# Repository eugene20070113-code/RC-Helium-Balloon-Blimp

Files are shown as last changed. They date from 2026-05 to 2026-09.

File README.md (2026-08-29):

# RC-Helium-Balloon-Blimp

ESP32-C3 SuperMini based RC helium balloon blimp prototype. This project uses a DRV8833 motor driver to control two 720 coreless motors, and uses the Dabble mobile app GamePad module as the Bluetooth remote controller.

The current stage focuses on making the blimp move smoothly by using differential thrust. The left and right motors can run forward, backward, and at different speeds, allowing straight movement and wide-radius turning.

## Current Status

| Item | Current Setting |
| --- | --- |
| Main controller | ESP32-C3 SuperMini |
| Motor driver | DRV8833 |
| Motors | Two 720 coreless motors |
| Remote-control app | Dabble |
| Dabble module | GamePad |
| Bluetooth device name | `Innovation_Balloon` |
| Development environment | VS Code + PlatformIO |
| PlatformIO environment | `esp32-c3-supermini` |
| Main firmware file | `src/main.cpp` |
| Arduino sketch copies | `sketch_may14a.ino`, `arduino/sketch_may14a/sketch_may14a.ino` |

## Main Design Idea

The blimp uses two side motors instead of a steering rudder. Movement is controlled by changing the thrust of the left and right motors:

- Forward: both motors push forward at the same speed.
- Backward: both motors reverse at the same speed.
- Left turn: right motor runs faster than the left motor.
- Right turn: left motor runs faster than the right motor.
- Arc movement: forward or backward movement is combined with left/right turning.

This turning method is more suitable for a helium blimp because it avoids sudden in-place spinning. The current firmware uses wide-radius turns so the motion is smoother and easier to control.

## Hardware List

#### Control Electronics
- ESP32-C3 SuperMini
- DRV8833 motor driver module
- External motor battery

#### Motors and Propulsion
- Two 720 coreless motors
- Orbz balloon (structural body)
- Helium (lifting gas)

#### Protection Components
- 104 ceramic capacitors (2x)
- 100uF electrolytic capacitor

#### Remote Control Options
- **Option 1**: Smartphone via Dabble app (Bluetooth)
- **Option 2**: ESP32 + Mushroom joystick transmitter

### Wiring

### 1. Power Center and Main Switch

The battery first goes through the slide switch, then enters the breadboard power rail. This makes the switch the main power control for the whole system.

| Wire / Pin | Destination | Purpose |
| --- | --- | --- |
| Battery black wire / negative | Breadboard blue GND rail | Common ground |
| Battery red wire / positive | Center pin of the 3-pin slide switch | Power input to switch |
| Left or right output pin of slide switch | Breadboard red VCC rail | Switched power output |

After this step, the breadboard red rail is the main `VCC`, and the blue rail is the main `GND`.

### 2. ESP32-C3 SuperMini Power

| ESP32-C3 SuperMini | Destination | Note |
| --- | --- | --- |
| 5V | Breadboard red VCC rail | Use this pin for the current wiring |
| GND | Breadboard blue GND rail | Shared ground |

Important: do not connect the main power rail to the ESP32-C3 `3V3` pin. The current wiring plan powers the board through `5V`.

### 3. DRV8833 Power and Enable

| DRV8833 Pin | Destination | Purpose |
| --- | --- | --- |
| VCC | Breadboard red VCC rail | Motor driver power |
| GND | Breadboard blue GND rail | Shared ground |
| EEP | Breadboard red VCC rail | Enable / wake line |

The `EEP` pin must be connected to VCC. If `EEP` is not connected, the DRV8833 may stay disabled and the motors will not run even if the signal wires are correct.

### 4. ESP32-C3 to DRV8833 Signal Wiring

| ESP32-C3 GPIO | DRV8833 Input | Firmware Constant | Motor Side |
| --- | --- | --- | --- |
| GPIO4 | IN1 | `IN1` | Left motor forward side |
| GPIO5 | IN2 | `IN2` | Left motor backward side |
| GPIO6 | IN3 | `IN3` | Right motor forward side |
| GPIO7 | IN4 | `IN4` | Right motor backward side |

The firmware uses `analogWrite()` on these pins to control motor speed through PWM.

### 5. Motor Output Wiring

| Motor | DRV8833 Output |
| --- | --- |
| Left 720 coreless motor | OUT1 and OUT2 |
| Right 720 coreless motor | OUT3 and OUT4 |

If one motor spins in the wrong direction, swap the two wires of that motor on the DRV8833 output. If both motors move backward when pressing forward, the direction can also be corrected in firmware.

## Capacitors and Protection

| Component | Placement | Polarity | Purpose |
| --- | --- | --- | --- |
| 100uF electrolytic capacitor | Near DRV8833, between VCC and GND rails | Long leg to VCC, short leg / stripe side to GND | Helps stabilize motor power |
| 104 ceramic capacitor | Across the left motor terminals | No polarity | Reduces motor electrical noise |
| 104 ceramic capacitor | Across the right motor terminals | No polarity | Reduces motor electrical noise |

The 720 coreless motors can create electrical noise and sudden current changes. The capacitors help reduce noise and make the power supply more stable, especially when the motors start moving.

### Remote Control

The blimp supports two wireless control methods:

#### Method 1: Smartphone (Dabble App)
- Uses Bluetooth wireless connection
- Control via mobile device running Dabble app
- Suitable for quick testing and demonstrations

#### Method 2: ESP32 + Mushroom Joystick
- Uses a separate ESP32 transmitter with mushroom joystick
- Direct wireless control between two ESP32 boards
- More ergonomic for extended flying sessions
- Better range and reliability for field operations

### Current Test Program

### Bluetooth Control

The firmware uses Dabble ESP32 with custom settings enabled:

```cpp
#define CUSTOM_SETTINGS
#define INCLUDE_GAMEPAD_MODULE
#include <DabbleESP32.h>
```

The Bluetooth name shown in the Dabble app is:

```cpp
Dabble.begin("Innovation_Balloon");
```

### Speed Settings

```cpp
const int CRUISE_SPEED = 255;
const int TURN_FAST_SPEED = 255;
const int TURN_SLOW_SPEED = 120;
const int RAMP_SPEED = 15;
```

| Constant | Meaning |
| --- | --- |
| `CRUISE_SPEED` | Speed used for straight forward/backward movement |
| `TURN_FAST_SPEED` | Speed of the outside motor during turning |
| `TURN_SLOW_SPEED` | Speed of the inside motor during turning |
| `RAMP_SPEED` | Maximum speed change per loop cycle |

PWM speed values range from `0` to `255`.

### Soft-Start / Smooth Acceleration

The firmware does not immediately jump from `0` to full speed. Instead, it stores the current motor speed in:

```cpp
int currentLeftSpeed = 0;
int currentRightSpeed = 0;
```

The `drive()` function gradually moves the current speed toward the target speed by `RAMP_SPEED`. This reduces sudden motor startup current and helps prevent ESP32-C3 resets caused by voltage drops.

### Control Behavior

| Dabble GamePad Input | Left Motor | Right Motor | Blimp Movement |
| --- | --- | --- | --- |
| Up | Forward fast | Forward fast | Straight forward |
| Down | Backward fast | Backward fast | Straight backward |
| Left | Forward slow | Forward fast | Wide left turn |
| Right | Forward fast | Forward slow | Wide right turn |
| Up + Left | Forward slow | Forward fast | Forward left arc |
| Up + Right | Forward fast | Forward slow | Forward right arc |
| Down + Left | Backward slow | Backward fast | Backward left arc |
| Down + Right | Backward fast | Backward slow | Backward right arc |
| No button | Ramps down to 0 | Ramps down to 0 | Smooth stop |

## PlatformIO / VS Code

This project is configured for VS Code with PlatformIO.

| Setting | Value |
| --- | --- |
| PlatformIO environment | `esp32-c3-supermini` |
| Board | `esp32-c3-devkitm-1` |
| Framework | Arduino |
| Upload port | `COM10` |
| Monitor port | `COM10` |
| Monitor speed | `115200` |

Build command:

```powershell
C:\Users\01034\.platformio\penv\Scripts\pio.exe run
```

The latest build result was successful.

## Testing Checklist

1. Confirm the battery negative line is connected to the breadboard GND rail.
2. Confirm the battery positive line goes through the slide switch before reaching the VCC rail.
3. Confirm ESP32-C3 uses `5V` and `GND`.
4. Confirm DRV8833 `VCC`, `GND`, and `EEP` are connected.
5. Confirm GPIO4, GPIO5, GPIO6, and GPIO7 match IN1, IN2, IN3, and IN4.
6. Confirm the 100uF capacitor polarity is correct.
7. Confirm each 104 capacitor is soldered across the motor terminals.
8. Upload the firmware.
9. Open Dabble and connect to `Innovation_Balloon`.
10. Test without propellers first.
11. Press each direction button briefly and confirm the motor direction.

## Troubleshooting

| Problem | Possible Cause | Fix |
| --- | --- | --- |
| Motors do not move | DRV8833 `EEP` not connected | Connect `EEP` to VCC |
| ESP32-C3 resets when motors start | Motor startup current causes voltage drop | Check capacitor, battery strength, and lower speed/ramp settings |
| One motor spins backward | Motor output wires reversed | Swap the two wires of that motor |
| Left/right control feels reversed | Motor side or output direction is reversed | Swap motor wires or adjust firmware |
| Dabble cannot find the board | Bluetooth not started or wrong board powered | Check ESP32-C3 power and look for `Innovation_Balloon` |
| Upload fails | Wrong COM port | Check Device Manager or PlatformIO port setting |

## Progress Reports

- [2026-05-29 Dabble Remote Control and Final Wiring](docs/progress-2026-05-29.md)
- [2026-05-26 Current Progress Report](docs/progress-2026-05-26.md)
- [2026-05-22 Differential Motor Test](docs/progress-2026-05-22.md)

## Safety Notes

This project can be opened in VS Code with PlatformIO.

- Environment: `esp32-c3-supermini`
- Upload port: `COM10`
- Serial monitor speed: `115200`

### Arduino IDE

The same logic is also available in the Arduino IDE sketch:

`arduino/sketch_may14a/sketch_may14a.ino`

---

## 📄 License

This project is licensed under the MIT License - see the [LICENSE](LICENSE) file for details.

---

## 📞 Contact & Support

If you have any technical questions or suggestions, please contact us through:
- 📧 Email: eugene20070113@gmail.com
- 💬 Issues: [GitHub Issues](https://github.com/eugene20070113-code/RC-Helium-Balloon-Blimp/issues)

---

## 中文

### 專案簡介

本專案是使用 ESP32-C3 SuperMini 製作的氦氣飛船馬達控制原型。系統透過 DRV8833 馬達驅動模組控制兩顆 720 空心杯馬達。兩顆馬達分別安裝在飛船左右兩側，藉由左右推力差實現前進、後退與轉向。

### 使用硬體

#### 控制電子元件
- ESP32-C3 SuperMini
- DRV8833 馬達驅動模組
- 外接馬達電池

#### 馬達與推進系統
- 兩顆 720 空心杯馬達
- Orbz 氣球（結構體）
- 氦氣（升力氣體）

#### 保護元件
- 104 陶瓷電容 (2個)
- 100uF 電解電容

#### 遙控方式
- **方案 1**：手機 Dabble app 遙控（藍牙無線）
- **方案 2**：ESP32 + 蘑菇搖桿遙控

### 接線

#### ESP32-C3 接 DRV8833

| ESP32-C3 SuperMini | DRV8833 | 說明 |
| --- | --- | --- |
| GPIO4 | IN1 | 左馬達控制 1 |
| GPIO5 | IN2 | 左馬達控制 2 |
| GPIO6 | IN3 | 右馬達控制 1 |
| GPIO7 | IN4 | 右馬達控制 2 |
| 3V3 | EEP | 啟用 DRV8833 |
| GND | GND | 共地 |

#### 馬達與電源

| DRV8833 | 接法 |
| --- | --- |
| VCC | 馬達電池正極 |
| GND | 馬達電池負極 |
| OUT1, OUT2 | 左馬達 |
| OUT3, OUT4 | 右馬達 |

ESP32-C3 的 GND、DRV8833 的 GND、馬達電池負極必須接在一起，也就是共地。

### 電容配置

| 元件 | 位置 | 作用 |
| --- | --- | --- |
| 104 陶瓷電容 | 並聯在左馬達兩端 | 降低馬達雜訊 |
| 104 陶瓷電容 | 並聯在右馬達兩端 | 降低馬達雜訊 |
| 100uF 電解電容 | 接在 DRV8833 VCC 與 GND 之間 | 穩定馬達電源 |

104 陶瓷電容沒有正負極。100uF 電解電容有正負極，正極接 DRV8833 VCC，負極接 DRV8833 GND。

### 遙控控制

飛船支援兩種無線控制方式：

#### 方案 1：手機 Dabble App
- 使用藍牙無線連接
- 透過執行 Dabble app 的手機進行控制
- 適合快速測試與演示

#### 方案 2：ESP32 + 蘑菇搖桿
- 使用另一塊 ESP32 搭配蘑菇搖桿作為發射器
- 兩塊 ESP32 之間的直接無線控制
- 操作更符合人體工學，適合長時間飛行
- 可提供更好的控制距離與可靠性

### 目前測試程式

目前程式會依照以下順序測試馬達：

1. 前進：左右馬達都以速度 `150` 正轉 1.5 秒。
2. 停止 2 秒。
3. 後退：左右馬達都以速度 `150` 反轉 1.5 秒。
4. 停止 2 秒。
5. 左轉：左馬達速度 `80`，右馬達速度 `170`，持續 1.5 秒。
6. 停止 2 秒。
7. 右轉：左馬達速度 `170`，右馬達速度 `80`，持續 1.5 秒。
8. 停止 3 秒後重複。

### PWM 速度設定

目前使用 PWM 控制馬達速度，數值範圍是 `0` 到 `255`。

```cpp
const int CRUISE_SPEED = 150;
const int TURN_SLOW_SPEED = 80;
const int TURN_FAST_SPEED = 170;
```

### 安全注意事項

- 初期桌上測試時不要安裝螺旋槳。
- 確認測試動作後，請拔掉馬達電池。
- 不要讓測試程式長時間連續運轉。
- 如果驅動板、馬達或電池明顯發熱，請立刻斷電。

### 進度報告

- [2026-05-22 雙馬達差速測試](docs/progress-2026-05-22.md)

### PlatformIO / VS Code

本專案可以使用 VS Code 搭配 PlatformIO 開啟。

- 環境：`esp32-c3-supermini`
- 燒錄埠：`COM10`
- 序列監控鮑率：`115200`

### Arduino IDE

相同邏輯也有 Arduino IDE 版本：

`arduino/sketch_may14a/sketch_may14a.ino`

---

## 📄 授權條款

本專案採用 MIT License 授權 - 詳見 [LICENSE](LICENSE) 文件。

---

## 📞 聯絡與支援

如有技術問題或建議，請通過以下方式聯絡：
- 📧 Email: eugene20070113@gmail.com
- 💬 Issues: [GitHub Issues](https://github.com/eugene20070113-code/RC-Helium-Balloon-Blimp/issues)

---

**Last Updated**: 2026年8月29日

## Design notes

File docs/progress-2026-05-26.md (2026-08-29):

# 2026-05-26 目前進度報告

日期：2026-05-26  
專案：RC Helium Balloon Blimp / 氦氣飛船馬達控制原型

## 1. 專案目標

本專案目前目標是製作一台以 ESP32-C3 SuperMini 為主控板的氦氣飛船原型，使用 DRV8833 馬達驅動模組控制左右兩顆 720 空心杯馬達。透過左右馬達不同推力，讓飛船可以完成前進、後退、左轉與右轉。

目前階段重點不是完整遙控，而是先確認「雙馬達差速控制」是否穩定可用。

## 2. 目前硬體配置

目前使用的主要零件如下：

| 零件 | 用途 |
| --- | --- |
| ESP32-C3 SuperMini | 主控板 |
| DRV8833 馬達驅動模組 | 控制左右兩顆馬達 |
| 720 空心杯馬達 x 2 | 左右推進馬達 |
| 104 陶瓷電容 x 2 | 降低馬達雜訊 |
| 100uF 電解電容 | 穩定馬達電源 |
| 外接馬達電池 | 提供馬達電源 |

## 3. 目前接線狀態

### ESP32-C3 SuperMini 與 DRV8833

| ESP32-C3 SuperMini | DRV8833 | 說明 |
| --- | --- | --- |
| GPIO4 | IN1 | 左馬達控制腳 1 |
| GPIO5 | IN2 | 左馬達控制腳 2 |
| GPIO6 | IN3 | 右馬達控制腳 1 |
| GPIO7 | IN4 | 右馬達控制腳 2 |
| 3V3 | EEP | 啟用 DRV8833 |
| GND | GND | 共地 |

### 馬達與電源

| DRV8833 | 連接位置 |
| --- | --- |
| VCC | 馬達電池正極 |
| GND | 馬達電池負極 |
| OUT1, OUT2 | 左馬達 |
| OUT3, OUT4 | 右馬達 |

ESP32-C3 的 GND、DRV8833 的 GND、馬達電池負極需要共地，否則控制訊號可能不穩定。

## 4. 電容安裝規劃

| 電容 | 安裝位置 | 目的 |
| --- | --- | --- |
| 104 陶瓷電容 | 並聯在左馬達兩端 | 降低馬達電刷雜訊 |
| 104 陶瓷電容 | 並聯在右馬達兩端 | 降低馬達電刷雜訊 |
| 100uF 電解電容 | 接在 DRV8833 VCC 與 GND 之間 | 穩定馬達供電 |

104 陶瓷電容沒有正負極。100uF 電解電容有正負極，正極接 DRV8833 VCC，負極接 DRV8833 GND。

## 5. 目前韌體狀態

目前程式已從原本的 Dabble 手機藍牙遙控測試，改成 DRV8833 雙馬達差速測試程式。

目前主要程式檔案：

| 檔案 | 狀態 |
| --- | --- |
| `src/main.cpp` | PlatformIO 主要編譯入口，目前是雙馬達差速測試版 |
| `sketch_may14a.ino` | Arduino sketch，目前也是雙馬達差速測試版 |
| `arduino/sketch_may14a/sketch_may14a.ino` | Arduino IDE 版本，同樣是雙馬達差速測試版 |
| `platformio.ini` | PlatformIO 設定，目標板為 ESP32-C3 |

目前 PlatformIO 設定如下：

```ini
[env:esp32-c3-supermini]
platform = espressif32
board = esp32-c3-devkitm-1
framework = arduino
upload_port = COM10
monitor_port = COM10
monitor_speed = 115200
```

## 6. 目前測試程式內容

目前韌體會自動循環執行以下動作：

1. 前進：左右馬達同時以速度 `150` 正轉 1.5 秒。
2. 停止 2 秒。
3. 後退：左右馬達同時以速度 `150` 反轉 1.5 秒。
4. 停止 2 秒。
5. 左轉：左馬達速度 `80`，右馬達速度 `170`，持續 1.5 秒。
6. 停止 2 秒。
7. 右轉：左馬達速度 `170`，右馬達速度 `80`，持續 1.5 秒。
8. 停止 3 秒，然後重複。

目前 PWM 速度設定：

```cpp
const int CRUISE_SPEED = 150;
const int TURN_SLOW_SPEED = 80;
const int TURN_FAST_SPEED = 170;
```

PWM 範圍是 `0` 到 `255`。目前速度設定偏保守，適合桌上測試與初期調機。

## 7. 目前完成項目

- 已建立 ESP32-C3 SuperMini + DRV8833 的雙馬達控制架構。
- 已將控制腳位整理為 GPIO4、GPIO5、GPIO6、GPIO7。
- 已加入左右馬達獨立 PWM 控制函式。
- 已完成前進、後退、左轉、右轉、停止等基本動作函式。
- 已將 PlatformIO 版本 `src/main.cpp` 與 Arduino sketch 版本保持為同一套測試邏輯。
- 已整理目前硬體接線與測試流程，方便放到 GitHub 追蹤進度。

## 8. 目前待確認項目

- 目前本機 PowerShell 找不到 `pio` 指令，因此這次尚未能用終端機執行 `pio run` 重新編譯驗證。
- 若使用 VS Code 的 PlatformIO 擴充套件，仍可嘗試從 PlatformIO 介面進行 Build / Upload。
- 需要實機確認左右馬達方向是否與程式假設一致。
- 需要確認左轉與右轉在實際飛船架構上是否符合預期。
- 需要確認 104 陶瓷電容與 100uF 電解電容是否已正確安裝。
- Git 工作區目前不是乾淨狀態，`sketch_may14a.ino` 有修改，且 `RC-Helium-Balloon-Blimp/` 是尚未追蹤的新資料夾。

## 9. 安全注意事項

- 初期測試建議不要安裝螺旋槳，避免馬達突然轉動造成危險。
- 每次測試完應拔除馬達電池。
- 如果 DRV8833、馬達或電池明顯發熱，應立即斷電。
- 不建議讓目前自動測試程式長時間連續運轉。
- 裝上螺旋槳前，應先確認馬達方向與轉向邏輯。

## 10. 下一步建議

1. 用 VS Code PlatformIO 或可用的 PlatformIO CLI 重新 Build，確認目前程式可編譯。
2. 上傳到 ESP32-C3，觀察序列埠輸出是否依序顯示 Forward、Backward、Turn left、Turn right。
3. 不裝螺旋槳，先確認左右馬達是否依照測試流程轉動。
4. 若方向相反，先交換馬達線或調整 `setMotor()` / `turnLeft()` / `turnRight()` 的控制邏輯。
5. 將馬達固定到飛船架構後，重新測試推力方向。
6. 調整 `CRUISE_SPEED`、`TURN_SLOW_SPEED`、`TURN_FAST_SPEED`，找出穩定且不過熱的速度。
7. 馬達控制穩定後，再加入手機藍牙或其他遙控方式。

## 11. 目前結論

截至 2026-05-26，專案已進入「雙馬達差速控制測試」階段。程式架構已經從單一馬達或 Dabble 遙控測試，轉為可控制左右兩顆馬達的自動測試流程。

目前最重要的下一步是完成編譯與實機測試，確認馬達方向、轉向邏輯與供電穩定性。確認雙馬達控制穩定後，才適合繼續整合遙控功能與飛船本體測試。

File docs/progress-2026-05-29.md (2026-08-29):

# Progress Report - 2026-05-29

Date: 2026-05-29

## English

### 1. Project Stage

The RC helium balloon blimp project has moved from basic two-motor testing to Bluetooth remote-control testing.

Before this update, the project mainly verified whether the ESP32-C3 SuperMini could drive two 720 coreless motors through the DRV8833 motor driver. Today, the firmware and wiring plan were updated so the motors can be controlled by the Dabble mobile app GamePad module.

The goal of this stage is to make the blimp easier to control before real flight testing. Instead of only running a fixed motor test sequence, the operator can now send live control commands from a phone.

### 2. Completed Hardware Wiring Plan

#### 2.1 Power Center and Main Switch

The battery is connected through a 3-pin slide switch before powering the breadboard rail. This gives the system a simple main power switch.

| Connection | Destination | Purpose |
| --- | --- | --- |
| Battery black wire / negative | Breadboard blue GND rail | Main ground line |
| Battery red wire / positive | Center pin of the 3-pin slide switch | Power input to switch |
| Slide switch output pin | Breadboard red VCC rail | Switched power output |

After this wiring, the breadboard red rail is treated as the main `VCC`, and the blue rail is treated as the main `GND`.

#### 2.2 ESP32-C3 SuperMini Power

| ESP32-C3 SuperMini | Destination | Note |
| --- | --- | --- |
| 5V | Breadboard red VCC rail | Main power input for the ESP32-C3 |
| GND | Breadboard blue GND rail | Shared ground |

Important note: the ESP32-C3 is connected through the `5V` pin in this wiring plan. The main power rail must not be connected to the `3V3` pin.

#### 2.3 DRV8833 Motor Driver and Enable Line

| DRV8833 Pin | Destination | Purpose |
| --- | --- | --- |
| VCC | Breadboard red VCC rail | Power input for motor driver |
| GND | Breadboard blue GND rail | Shared ground |
| EEP | Breadboard red VCC rail | Enable / wake line |

The `EEP` pin is required. If this pin is not connected to VCC, the DRV8833 can remain disabled and the motors may not move even when the control signals are correct.

#### 2.4 Capacitor Protection

| Component | Placement | Polarity | Purpose |
| --- | --- | --- | --- |
| 100uF electrolytic capacitor | Near the DRV8833 power rail | Long leg to VCC, short leg / stripe side to GND | Helps stabilize power during motor startup |
| 104 ceramic capacitor | Across the left motor terminals | No polarity | Reduces motor electrical noise |
| 104 ceramic capacitor | Across the right motor terminals | No polarity | Reduces motor electrical noise |

The 100uF capacitor is placed near the DRV8833 because the motors can draw sudden current when starting. The capacitor helps reduce voltage drops. The 104 ceramic capacitors are soldered directly across the motor terminals to reduce motor noise.

#### 2.5 Signal Wiring

| ESP32-C3 GPIO | DRV8833 Input | Firmware Constant | Function |
| --- | --- | --- | --- |
| GPIO4 | IN1 | `IN1` | Left motor forward control |
| GPIO5 | IN2 | `IN2` | Left motor backward control |
| GPIO6 | IN3 | `IN3` | Right motor forward control |
| GPIO7 | IN4 | `IN4` | Right motor backward control |

#### 2.6 Motor Output

| Motor | DRV8833 Output |
| --- | --- |
| Left 720 coreless motor | OUT1 and OUT2 |
| Right 720 coreless motor | OUT3 and OUT4 |

If a motor direction is reversed during testing, the two output wires of that motor can be swapped.

### 3. Firmware Files Updated

The same motor-control logic was updated in the PlatformIO firmware and Arduino sketch copies.

| File | Purpose |
| --- | --- |
| `src/main.cpp` | Main PlatformIO firmware used by VS Code |
| `sketch_may14a.ino` | Root Arduino sketch copy |
| `arduino/sketch_may14a/sketch_may14a.ino` | Arduino IDE sketch folder copy |
| `README.md` | Project wiring and usage documentation |
| `docs/progress-2026-05-29.md` | Today's progress report |

### 4. Firmware Changes

#### 4.1 Dabble GamePad Control

The firmware now uses the Dabble ESP32 library and only enables the GamePad module:

```cpp
#define CUSTOM_SETTINGS
#define INCLUDE_GAMEPAD_MODULE
#include <DabbleESP32.h>
```

The Bluetooth device name was updated to:

```cpp
Dabble.begin("Innovation_Balloon");
```

This is the name that should appear in the Dabble app when connecting from the phone.

#### 4.2 Motor Pin Definitions

The motor control pins are:

```cpp
const int IN1 = 4;
const int IN2 = 5;
const int IN3 = 6;
const int IN4 = 7;
```

These match the ESP32-C3 to DRV8833 signal wiring.

#### 4.3 Speed Settings

The current speed settings are:

```cpp
const int CRUISE_SPEED = 255;
const int TURN_FAST_SPEED = 255;
const int TURN_SLOW_SPEED = 120;
```

`CRUISE_SPEED` is used for straight movement. `TURN_FAST_SPEED` is used by the outside motor while turning. `TURN_SLOW_SPEED` is used by the inside motor while turning.

The current values are intentionally strong for testing motor response. These values may need to be reduced after the motors are installed on the actual blimp frame.

#### 4.4 Smooth Acceleration

The firmware now tracks actual motor output speed:

```cpp
int currentLeftSpeed = 0;
int currentRightSpeed = 0;
```

The ramp value is:

```cpp
const int RAMP_SPEED = 15;
```

Instead of instantly jumping to the target speed, the `drive()` function gradually increases or decreases the motor speed. This reduces sudden current draw and helps prevent power drop or ESP32-C3 reset when the motors start.

#### 4.5 Motor Output Function

The `setMotor()` function receives a speed value from `-255` to `255`.

- Positive speed: motor turns forward.
- Negative speed: motor turns backward.
- Zero speed: motor stops.

This makes the motor control easier to read because forward and backward movement can be represented by the sign of the speed value.

### 5. Control Logic

The `handleGamePad()` function reads the Dabble GamePad buttons:

```cpp
bool up = GamePad.isUpPressed();
bool down = GamePad.isDownPressed();
bool left = GamePad.isLeftPressed();
bool right = GamePad.isRightPressed();
```

Then it calculates target speed for the left and right motors.

| Dabble Input | Left Motor Target | Right Motor Target | Result |
| --- | --- | --- | --- |
| Up | `CRUISE_SPEED` | `CRUISE_SPEED` | Straight forward |
| Down | `-CRUISE_SPEED` | `-CRUISE_SPEED` | Straight backward |
| Left | `TURN_SLOW_SPEED` | `TURN_FAST_SPEED` | Wide left turn |
| Right | `TURN_FAST_SPEED` | `TURN_SLOW_SPEED` | Wide right turn |
| Up + Left | `TURN_SLOW_SPEED` | `TURN_FAST_SPEED` | Forward left arc |
| Up + Right | `TURN_FAST_SPEED` | `TURN_SLOW_SPEED` | Forward right arc |
| Down + Left | `-TURN_SLOW_SPEED` | `-TURN_FAST_SPEED` | Backward left arc |
| Down + Right | `-TURN_FAST_SPEED` | `-TURN_SLOW_SPEED` | Backward right arc |
| No button | `0` | `0` | Smooth stop |

The single left and right buttons do not perform sharp in-place rotation. Instead, both motors keep moving forward, but one side is slower. This creates a smoother and wider turning radius, which is more suitable for a helium blimp.

### 6. Current Result

The updated firmware is now in the VS Code / PlatformIO project. The PlatformIO build was tested successfully.

Build command used:

```powershell
C:\Users\01034\.platformio\penv\Scripts\pio.exe run
```

Build result:

```text
[SUCCESS] Took 18.30 seconds
```

This confirms that the updated `src/main.cpp` compiles correctly with the current PlatformIO setup and DabbleESP32 library.

### 7. Testing Plan

Recommended test sequence:

1. Confirm all power is off.
2. Check the battery negative line is connected to the GND rail.
3. Check the battery positive line enters the slide switch first.
4. Check the slide switch output goes to the VCC rail.
5. Check ESP32-C3 `5V` and `GND`.
6. Check DRV8833 `VCC`, `GND`, and `EEP`.
7. Check GPIO4 to IN1, GPIO5 to IN2, GPIO6 to IN3, and GPIO7 to IN4.
8. Check 100uF capacitor polarity.
9. Check both 104 capacitors on the motors.
10. Upload the firmware.
11. Open Dabble and connect to `Innovation_Balloon`.
12. Test each direction without propellers.
13. Confirm forward, backward, left arc, and right arc.
14. If a direction is wrong, fix motor wiring or adjust firmware direction.

### 8. Problems to Watch For

| Problem | Possible Cause | Fix |
| --- | --- | --- |
| Motors do not move | DRV8833 `EEP` is not connected | Connect `EEP` to VCC |
| ESP32-C3 restarts when motors start | Voltage drop from motor startup current | Check battery, capacitor, and reduce speed/ramp settings |
| One motor direction is reversed | Motor output wires are reversed | Swap the two output wires of that motor |
| Left and right controls are reversed | Motor sides or output direction are reversed | Swap motor connections or adjust code |
| Dabble cannot connect | Bluetooth name not found or ESP32 not powered | Check power and search for `Innovation_Balloon` |
| Motor noise affects control | Capacitors missing or wiring too loose | Recheck 104 capacitors and common ground |

### 9. Next Steps

1. Upload the firmware to the ESP32-C3 through PlatformIO.
2. Test Dabble connection and button response.
3. Test motor direction without propellers.
4. Mount the motors on the blimp frame.
5. Test the same controls after mounting.
6. Tune `CRUISE_SPEED`, `TURN_FAST_SPEED`, and `TURN_SLOW_SPEED`.
7. Tune `RAMP_SPEED` if acceleration is too slow or still causes power drops.
8. Record real flight-frame test results in the next progress report.

## 中文

### 1. 專案階段

RC 氦氣飛船專案今天從「雙馬達基本測試」進入「藍牙遙控測試」階段。

前一階段主要確認 ESP32-C3 SuperMini 是否能透過 DRV8833 馬達驅動模組控制兩顆 720 空心杯馬達。今天的重點是把固定測試流程改成手機即時遙控，讓操作者可以透過 Dabble App 的 GamePad 模組控制飛船前進、後退與轉向。

這個階段的目標是讓飛船在實際飛行測試前，先具備比較穩定、可重複操作的遙控能力。

### 2. 今日完成的硬體接線規劃

#### 2.1 能源中心與總開關

電池會先進入 3 腳滑動開關，再由開關輸出到麵包板電源軌。這樣整個系統就有一個主電源開關。

| 接線 | 接到 | 目的 |
| --- | --- | --- |
| 電池黑線 / 負極 | 麵包板藍色總地線軌 GND | 系統共同地線 |
| 電池紅線 / 正極 | 3 腳滑動開關的正中間腳位 | 開關電源輸入 |
| 滑動開關左邊或右邊輸出腳 | 麵包板紅色總電源軌 VCC | 開關後的系統電源 |

完成後，麵包板紅色軌視為整個系統的 `VCC`，藍色軌視為整個系統的 `GND`。

#### 2.2 ESP32-C3 SuperMini 供電

| ESP32-C3 SuperMini | 接到 | 說明 |
| --- | --- | --- |
| 5V | 麵包板紅色總電源軌 VCC | 目前接線使用的供電腳 |
| GND | 麵包板藍色總地線軌 GND | 與馬達驅動共地 |

重要注意：目前接法是把電源接到 ESP32-C3 的 `5V` 腳位，絕對不能把主電源軌接到 `3V3` 腳位。

#### 2.3 DRV8833 馬達驅動與喚醒線

| DRV8833 腳位 | 接到 | 目的 |
| --- | --- | --- |
| VCC | 麵包板紅色總電源軌 VCC | 馬達驅動電源 |
| GND | 麵包板藍色總地線軌 GND | 系統共同地線 |
| EEP | 麵包板紅色總電源軌 VCC | 啟用 / 喚醒 DRV8833 |

`EEP` 是非常重要的喚醒線。若沒有接到 VCC，DRV8833 可能會維持關閉狀態，即使 ESP32-C3 有送控制訊號，馬達也不會動。

#### 2.4 電容防護

| 元件 | 位置 | 正負極 | 作用 |
| --- | --- | --- | --- |
| 100uF 電解電容 | 靠近 DRV8833 的 VCC 與 GND 電源軌之間 | 長腳接 VCC，短腳 / 白條紋側接 GND | 穩定馬達啟動時的電源 |
| 104 陶瓷電容 | 左馬達兩個接點之間 | 不分正負極 | 降低馬達雜訊 |
| 104 陶瓷電容 | 右馬達兩個接點之間 | 不分正負極 | 降低馬達雜訊 |

720 空心杯馬達啟動時可能會產生瞬間電流變化與電氣雜訊。100uF 電解電容用來幫助穩定供電，104 陶瓷電容則用來降低馬達端產生的雜訊。

#### 2.5 訊號線

| ESP32-C3 GPIO | DRV8833 輸入 | 程式常數 | 功能 |
| --- | --- | --- | --- |
| GPIO4 | IN1 | `IN1` | 左馬達前進控制 |
| GPIO5 | IN2 | `IN2` | 左馬達後退控制 |
| GPIO6 | IN3 | `IN3` | 右馬達前進控制 |
| GPIO7 | IN4 | `IN4` | 右馬達後退控制 |

#### 2.6 動力輸出

| 馬達 | DRV8833 輸出 |
| --- | --- |
| 左 720 空心杯馬達 | OUT1 與 OUT2 |
| 右 720 空心杯馬達 | OUT3 與 OUT4 |

如果測試時某一顆馬達方向相反，可以直接對調該馬達接在 DRV8833 輸出的兩條線。

### 3. 今日更新的檔案

| 檔案 | 用途 |
| --- | --- |
| `src/main.cpp` | VS Code / PlatformIO 使用的主要程式 |
| `sketch_may14a.ino` | 根目錄 Arduino sketch 備份 |
| `arduino/sketch_may14a/sketch_may14a.ino` | Arduino IDE sketch 資料夾版本 |
| `README.md` | 專案接線、功能與使用說明 |
| `docs/progress-2026-05-29.md` | 今日進度紀錄 |

### 4. 程式更新內容

#### 4.1 加入 Dabble GamePad 藍牙遙控

程式使用 Dabble ESP32 函式庫，並只啟用 GamePad 模組：

```cpp
#define CUSTOM_SETTINGS
#define INCLUDE_GAMEPAD_MODULE
#include <DabbleESP32.h>
```

藍牙裝置名稱設定為：

```cpp
Dabble.begin("Innovation_Balloon");
```

手機 Dabble App 連線時，應該尋找 `Innovation_Balloon` 這個名稱。

#### 4.2 馬達腳位定義

目前程式使用的馬達控制腳位如下：

```cpp
const int IN1 = 4;
const int IN2 = 5;
const int IN3 = 6;
const int IN4 = 7;
```

這四個腳位對應到 ESP32-C3 與 DRV8833 的訊號接線。

#### 4.3 速度參數

目前速度設定如下：

```cpp
const int CRUISE_SPEED = 255;
const int TURN_FAST_SPEED = 255;
const int TURN_SLOW_SPEED = 120;
```

`CRUISE_SPEED` 用於直線前進或後退。`TURN_FAST_SPEED` 是轉彎時外側馬達的速度。`TURN_SLOW_SPEED` 是轉彎時內側馬達的速度。

目前數值偏向測試最大推力與馬達反應。實際裝上飛船後，可能需要依照飛船重量、浮力、螺旋槳方向與電池狀態再調整。

#### 4.4 新增軟啟動與平滑加減速

程式新增兩個變數，用來記錄目前實際輸出的馬達速度：

```cpp
int currentLeftSpeed = 0;
int currentRightSpeed = 0;
```

加減速步進值設定為：

```cpp
const int RAMP_SPEED = 15;
```

馬達不會從 `0` 瞬間跳到 `255`，而是每次 loop 慢慢靠近目標速度。這樣可以降低啟動瞬間電流，讓 ESP32-C3 比較不容易因為電壓下降而重啟或斷電。

#### 4.5 馬達輸出函式

`setMotor()` 使用 `-255` 到 `255` 的速度值控制馬達：

- 正數代表正轉。
- 負數代表反轉。
- `0` 代表停止。

這樣設計後，前進與後退可以用速度的正負號表示，程式邏輯會比較清楚。

### 5. 遙控邏輯

`handleGamePad()` 會讀取 Dabble GamePad 的四個方向鍵：

```cpp
bool up = GamePad.isUpPressed();
bool down = GamePad.isDownPressed();
bool left = GamePad.isLeftPressed();
bool right = GamePad.isRightPressed();
```

接著依照按鍵組合計算左右馬達的目標速度。

| Dabble 輸入 | 左馬達目標 | 右馬達目標 | 飛船動作 |
| --- | --- | --- | --- |
| 上 | `CRUISE_SPEED` | `CRUISE_SPEED` | 直線前進 |
| 下 | `-CRUISE_SPEED` | `-CRUISE_SPEED` | 直線後退 |
| 左 | `TURN_SLOW_SPEED` | `TURN_FAST_SPEED` | 大半徑左轉 |
| 右 | `TURN_FAST_SPEED` | `TURN_SLOW_SPEED` | 大半徑右轉 |
| 上 + 左 | `TURN_SLOW_SPEED` | `TURN_FAST_SPEED` | 前進左弧線 |
| 上 + 右 | `TURN_FAST_SPEED` | `TURN_SLOW_SPEED` | 前進右弧線 |
| 下 + 左 | `-TURN_SLOW_SPEED` | `-TURN_FAST_SPEED` | 後退左弧線 |
| 下 + 右 | `-TURN_FAST_SPEED` | `-TURN_SLOW_SPEED` | 後退右弧線 |
| 無按鍵 | `0` | `0` | 平滑減速停止 |

單獨按左或右時，程式不是讓馬達原地反轉，而是讓左右兩顆馬達都往前轉，只是內側馬達較慢。這樣會形成比較自然的大半徑轉彎，比較適合氦氣飛船這種慣性較大、轉向不適合太急的載具。

### 6. 目前成果

最新版程式已經放入 VS Code / PlatformIO 專案中，並同步更新 Arduino sketch 備份。

使用的編譯指令：

```powershell
C:\Users\01034\.platformio\penv\Scripts\pio.exe run
```

編譯結果：

```text
[SUCCESS] Took 18.30 seconds
```

這代表 `src/main.cpp` 可以在目前 PlatformIO 環境下成功編譯，DabbleESP32 函式庫也有被正確引用。

### 7. 建議測試流程

1. 確認電源關閉。
2. 檢查電池黑線是否接到 GND 軌。
3. 檢查電池紅線是否先進入滑動開關中間腳。
4. 檢查滑動開關輸出是否接到 VCC 軌。
5. 檢查 ESP32-C3 是否接 `5V` 與 `GND`。
6. 檢查 DRV8833 的 `VCC`、`GND`、`EEP` 是否都有接好。
7. 檢查 GPIO4 到 IN1、GPIO5 到 IN2、GPIO6 到 IN3、GPIO7 到 IN4。
8. 檢查 100uF 電解電容正負極是否正確。
9. 檢查左右馬達是否各焊一顆 104 陶瓷電容。
10. 上傳最新版程式。
11. 開啟 Dabble App，連線 `Innovation_Balloon`。
12. 不安裝螺旋槳，先短按每個方向鍵測試馬達方向。
13. 確認前進、後退、左弧線、右弧線是否符合預期。
14. 若方向錯誤，先修正馬達線或程式方向，再進行下一步測試。

### 8. 可能遇到的問題

| 問題 | 可能原因 | 解決方式 |
| --- | --- | --- |
| 馬達完全不動 | DRV8833 `EEP` 沒有接到 VCC | 將 `EEP` 接到紅色 VCC 電源軌 |
| ESP32-C3 一啟動馬達就重啟 | 馬達啟動電流造成電壓下降 | 檢查電池、100uF 電容，或降低速度 / 調小加速幅度 |
| 某一顆馬達方向相反 | 馬達輸出線接反 | 對調該馬達的兩條線 |
| 左右控制相反 | 左右馬達位置或方向相反 | 對調左右馬達接線，或在程式調整方向 |
| Dabble 找不到裝置 | ESP32-C3 沒有正常供電或藍牙未啟動 | 檢查電源，重新搜尋 `Innovation_Balloon` |
| 馬達干擾導致控制不穩 | 電容未裝好或共地不良 | 檢查 104 電容、100uF 電容與 GND 共地 |

### 9. 下一步

1. 使用 PlatformIO 將程式上傳到 ESP32-C3。
2. 使用 Dabble App 實際連線測試。
3. 在不裝螺旋槳的情況下確認馬達方向。
4. 將馬達固定到飛船架構上。
5. 在飛船架構上再次測試前進、後退與轉向。
6. 根據飛船重量與推力調整 `CRUISE_SPEED`、`TURN_FAST_SPEED`、`TURN_SLOW_SPEED`。
7. 若起步仍然造成電壓下降，繼續調整 `RAMP_SPEED`。
8. 將實際裝機測試結果記錄到下一份進度報告。

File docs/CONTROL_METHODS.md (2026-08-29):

# 遙控控制方案詳解

本專案支援兩種無線遙控方案。本文件詳細說明每種方案的硬體配置、代碼部署和使用方式。

---

## 方案 1：手機 Dabble App 遙控 (Bluetooth)

### 特點
- ✅ 無需額外硬體
- ✅ 直接用手機控制
- ✅ 適合快速測試和演示
- ✅ 支援多種手機遊戲搖桿模擬

### 硬體需求
- 飛船：ESP32-C3 SuperMini
- 手機：iOS 或 Android
- 連接方式：Bluetooth 無線

### 軟體安裝
1. 手機下載 **Dabble** app
   - [iOS App Store](https://apps.apple.com/app/dabble-iot-for-arduino/id1461351821)
   - [Google Play Store](https://play.google.com/store/apps/details?id=io.dabble)

2. 飛船端代碼：`src/main.cpp` (原始測試版本)

### 使用流程
1. 將飛船代碼燒錄到 ESP32-C3 SuperMini
2. 打開手機 Dabble app
3. 點擊「Connect」搜尋藍牙設備
4. 選擇飛船的藍牙名稱並配對
5. 打開 Dabble 的「遊戲搖桿」功能
6. 用搖桿控制飛船的前進、後退、轉向

### 優點 & 缺點

| 方面 | 評價 |
|---|---|
| 成本 | 💰 最便宜（無需額外硬體） |
| 便利性 | ⭐⭐⭐⭐ 手機即拿即用 |
| 操控感 | ⭐⭐⭐ 可接受，但手機觸控不如物理搖桿 |
| 延遲 | ⚠️ 略高（Bluetooth 延遲約 50-100ms） |
| 有效距離 | 📍 ~10-15 公尺 |
| 適用場景 | 🏠 室內或近距離測試 |

---

## 方案 2：ESP32 + 香菇搖桿遙控 (ESP-NOW)

### 特點
- ✅ 專用硬體遙控器，操控更精確
- ✅ 香菇搖桿提供類比控制
- ✅ ESP-NOW 低延遲、高可靠性
- ✅ 更適合長時間飛行與精密操控

### 硬體需求

#### 飛船端 (接收器)
- **ESP32-C3 SuperMini**
- **DRV8833 馬達驅動模組**
- **2x 720 空心杯馬達**
- **Orbz 氣球**
- **保護元件**：2x 104 陶瓷電容 + 1x 100μF 電解電容

#### 遙控器端 (發射器)
- **ESP32** (大型版或 DevKit)
  - 需要模擬輸入腳位（ADC）
- **香菇搖桿模組**
  - VRx 連接 GPIO32
  - VRy 連接 GPIO33
  - +5V 和 GND 連接

### 硬體連接圖

#### 飛船端接線
```
ESP32-C3 SuperMini  ←→  DRV8833
GPIO4 (IN1)         ←→  IN1
GPIO5 (IN2)         ←→  IN2
GPIO6 (IN3)         ←→  IN3
GPIO7 (IN4)         ←→  IN4
3V3                 ←→  EEP
GND                 ←→  GND

DRV8833             ←→  馬達
OUT1, OUT2          ←→  左馬達
OUT3, OUT4          ←→  右馬達
VCC                 ←→  馬達電池 (+)
GND                 ←→  馬達電池 (-)
```

#### 遙控器端接線
```
香菇搖桿            ←→  ESP32
VRx                 ←→  GPIO32
VRy                 ←→  GPIO33
+5V                 ←→  5V
GND                 ←→  GND
```

### 代碼部署

#### 步驟 1：查詢飛船的 MAC 地址

1. 編譯並上傳飛船代碼：
   ```
   src/receiver_esp32_supermini/receiver.cpp
   ```

2. 打開 Serial Monitor（波特率：115200）

3. 查看輸出信息，找到飛船的 MAC 地址：
   ```
   🚁 飛船 ESP32-C3 SuperMini
   📡 MAC Address: 10:00:3B:CC:3E:6C
   ```

4. **記下這個 MAC 地址**（例如：10:00:3B:CC:3E:6C）

#### 步驟 2：配置遙控器代碼

1. 打開遙控器代碼：
   ```
   src/transmitter_esp32/transmitter.cpp
   ```

2. 找到這一行：
   ```cpp
   uint8_t broadcastAddress[] = {0xXX, 0xXX, 0xXX, 0xXX, 0xXX, 0xXX};
   ```

3. 根據步驟 1 的 MAC 地址替換：
   ```cpp
   // 範例：MAC 地址 10:00:3B:CC:3E:6C
   uint8_t broadcastAddress[] = {0x10, 0x00, 0x3B, 0xCC, 0x3E, 0x6C};
   ```

4. 保存並編譯

#### 步驟 3：燒錄代碼

1. 將飛船代碼燒錄到 **ESP32-C3 SuperMini**
2. 將遙控器代碼燒錄到 **ESP32 (遙控器)**
3. 分別打開兩個 Serial Monitor 查看狀態

### 使用流程

1. **啟動飛船**
   - 電源打開，飛船進入待機狀態
   - Serial Monitor 顯示：`⏳ 等待遙控器訊號...`

2. **啟動遙控器**
   - 打開遙控器電源
   - Serial Monitor 顯示：`✅ 遙控器已準備就緒！`
   - 等待與飛船配對

3. **開始控制**
   - 搖動香菇頭控制飛船
   - X 軸：左右轉向
   - Y 軸：前進/後退

4. **停止**
   - 將搖桿放回中心位置（自動歸零）
   - 如果超過 0.5 秒無訊號，飛船自動停止 (安全保護)

### 訊號協議

#### 訊號結構
```cpp
typedef struct struct_message {
  int x;           // 左右推力 (-255 到 255)
  int y;           // 前後推力 (-255 到 255)
  uint8_t checksum;// 校驗和 (防止訊號竄改)
} struct_message;
```

#### 校驗和機制
- 每個訊號都包含 CRC8 校驗和
- 接收端會驗證資料完整性
- 如果校驗失敗，訊號會被拒絕
- 這確保惡意或破損的訊號無法控制飛船

#### 更新頻率
- 遙控器每 20ms 發送一次訊號（~50 Hz）
- 飛船每 20ms 更新一次馬達控制
- 總延遲：< 50ms

### 優點 & 缺點

| 方面 | 評價 |
|---|---|
| 成本 | 💰💰 需購買額外硬體 (~USD 10-20) |
| 便利性 | ⭐⭐⭐⭐⭐ 專用搖桿，操控最直觀 |
| 操控感 | ⭐⭐⭐⭐⭐ 類比搖桿，精確度高 |
| 延遲 | ⚡ 極低 (< 50ms) |
| 有效距離 | 📍 ~100+ 公尺（取決於環境） |
| 適用場景 | 🌳 戶外飛行、長時間操控、精密控制 |

---

## 安全特性

### 所有方案共有

1. **斷訊保護**
   - 如果 0.5 秒內未收到訊號，飛船自動停止
   - 防止因連線中斷導致飛船失控

2. **死區防護**
   - 搖桿±20 以內的微小漂移被忽略
   - 防止手指離開搖桿時的無意輸入

3. **加速平滑**
   - 馬達速度逐步加速而非突然跳躍
   - 增加控制穩定性

4. **功率限制** (方案 2 特有)
   - 馬達速度被限制在 95-150 之間
   - 避免馬達在低電壓下發生故障

### 方案 2 額外安全機制

5. **校驗和驗證**
   - 每個訊號都有 CRC8 校驗和
   - 防止訊號竄改或損毀

6. **MAC 地址綁定**
   - 遙控器只能與指定的飛船通訊
   - 他人無法隨意控制你的飛船

---

## 控制邏輯說明

### 馬達混控系統

飛船採用「差分推力控制」，通過左右馬達速度差實現轉向：

```
leftMotor = throttle + steering
rightMotor = throttle - steering
```

- **throttle (X軸)**: 前進/後退
- **steering (Y軸)**: 左轉/右轉

### 轉向靈敏度

- 預設轉向靈敏度係數：`0.5`
- 這意味著轉向輸入會被削減一半
- 目的：確保轉向不會過度靈敏

如果你覺得轉向太靈或太遲鈍，可以修改這個值：
```cpp
const float STEERING_SENSITIVITY = 0.5;  // 改成 0.3 (更柔和) 或 0.7 (更靈敏)
```

---

## 故障排除

### 方案 1：Dabble 遙控

| 問題 | 解決方案 |
|---|---|
| 手機無法找到藍牙設備 | 檢查 ESP32 藍牙是否已啟用；嘗試重新啟動藍牙 |
| 控制延遲很高 | 靠近飛船；檢查是否有干擾；嘗試切換藍牙頻道 |
| 飛船不動 | 檢查馬達電池是否充電；確認所有接線無誤 |

### 方案 2：ESP32 + 搖桿遙控

| 問題 | 解決方案 |
|---|---|
| 遙控器找不到飛船 | 確認 MAC 地址是否正確；檢查飛船是否已上電 |
| Serial Monitor 顯示 "❌ MAC 地址未設置" | 用正確的飛船 MAC 替換 `0xXX` |
| 控制反應遲鈍 | 檢查搖桿是否損壞；嘗試重新校準ADC |
| 飛船突然停止 | 可能是訊號喪失 (斷訊保護)；檢查遙控器電源 |

---

## 推薦使用情景

### 選擇方案 1 (Dabble):
- 🏠 在家進行快速測試
- 👥 向朋友演示
- 📊 進行數據記錄和分析 (Dabble 有內建圖表)
- 🔧 調試馬達參數

### 選擇方案 2 (ESP32 + 搖桿):
- 🌳 戶外飛行測試
- ⏱️ 長時間操控 (搖桿不會因握持而疲勞)
- 🎯 精密飛行操控
- 🏆 競速或特技飛行

---

## 進階設置

### 修改馬達功率範圍

編輯 `receiver.cpp`：
```cpp
const int START_POWER = 95;       // 最低啟動推力
const int MAX_POWER = 150;        // 最高推力
```

- 降低 `MAX_POWER` → 飛船速度較慢但更穩定
- 提高 `MAX_POWER` → 飛船速度更快但消耗更多功率

### 調整轉向靈敏度

編輯 `receiver.cpp`：
```cpp
const float STEERING_SENSITIVITY = 0.5;
```

- 改成 `0.3` → 轉向變遲鈍 (適合初學者)
- 改成 `0.7` → 轉向變靈敏 (適合高手)

### 修改斷訊保護時間

編輯 `receiver.cpp`：
```cpp
if (millis() - lastRecvTime > 500) {  // 500ms
```

- 改成 `1000` → 允許 1 秒的訊號喪失時間
- 改成 `200` → 更靈敏的保護 (建議不要太短)

---

## 相關資源

- [ESP-NOW 官方文檔](https://docs.espressif.com/projects/esp-idf/en/latest/esp32/api-reference/network/esp_now.html)
- [Dabble 官方網站](https://thestempedia.com/dabble/)
- [ESP32 ADC 特性](https://docs.espressif.com/projects/esp-idf/en/latest/esp32/api-reference/peripherals/adc.html)

---

**最後更新**: 2026年8月29日

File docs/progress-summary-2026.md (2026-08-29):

# RC-Helium-Balloon-Blimp 專案進度總結

**最後更新**: 2026年8月29日

## 專案概述

RC直升機氣球/飛艇電機控制原型。使用ESP32-C3 SuperMini控制DRV8833馬達驅動器，以駕駛兩個720無芯馬達。

## 核心功能

- ✅ 雙馬達差分推力控制
- ✅ PWM速度控制（0-255）
- ✅ 前進、後退、轉向控制
- ✅ 馬達噪音減弱電路（去耦電容）

## 項目進度歷史

### 第1階段：初始設置 (提交: `df6b0e1`)
**狀態**: ✅ 完成
- 專案初始化
- 基礎硬體連線配置
- 文檔框架建立

**提交信息**: `feat: 完成單馬達藍牙遙控測試`

---

### 第2階段：單馬達藍牙遙控測試 (提交: `452175a`)
**狀態**: ✅ 完成
- 初始馬達測試專案建立
- 單馬達驅動測試
- 藍牙遙控基礎實現

**提交信息**: `Initial motor test project`

---

### 第3階段：差分馬達測試 (提交: `95198ef`)
**狀態**: ✅ 完成
- 升級為雙馬達控制
- 差分推力控制實現
- PWM速度控制參數設置

**測試序列**:
1. 前進：左右馬達速度150，1.5秒
2. 停止：2秒
3. 後退：左右馬達速度150，1.5秒
4. 停止：2秒
5. 左轉：左馬達速度80，右馬達速度170，1.5秒
6. 停止：2秒
7. 右轉：左馬達速度170，右馬達速度80，1.5秒
8. 停止：3秒

**測試結果**:
- ✅ 編譯成功
- ✅ 上傳成功
- ✅ 硬體檢測正常
- ✅ 馬達正常運作

**提交信息**: `Add differential motor test progress report`

---

### 第4階段：文檔改進 (提交: `366c047` - `23c984c`)
**狀態**: ✅ 完成
- 進度報告添加日期標記
- README.md雙語化（英文/中文）
- 文檔結構分離優化

**相關提交**:
- `366c047`: Add date to progress report
- `0e93481`: Make README bilingual
- `23c984c`: Separate English and Chinese documentation sections

---

## 硬體配置

### 主控制器
- **型號**: ESP32-C3 SuperMini
- **連接**: GPIO4-7 連接馬達驅動器

### 馬達驅動器
- **型號**: DRV8833 馬達驅動模塊
- **馬達**: 2x 720無芯馬達（左右側）

### 連線對應表

| ESP32-C3 | DRV8833 | 功能 |
|---|---|---|
| GPIO4 | IN1 | 左馬達控制1 |
| GPIO5 | IN2 | 左馬達控制2 |
| GPIO6 | IN3 | 右馬達控制1 |
| GPIO7 | IN4 | 右馬達控制2 |
| 3V3 | EEP | 啟用DRV8833 |
| GND | GND | 共同接地 |

### 保護元件

| 元件 | 位置 | 功能 |
|---|---|---|
| 104陶瓷電容 | 左馬達端子間 | 降低馬達電噪音 |
| 104陶瓷電容 | 右馬達端子間 | 降低馬達電噪音 |
| 100μF電解電容 | DRV8833 VCC/GND間 | 穩定馬達電源 |

## 當前韌體設置

### PWM速度參數
```cpp
const int CRUISE_SPEED = 150;      // 巡航速度
const int TURN_SLOW_SPEED = 80;    // 轉向慢速
const int TURN_FAST_SPEED = 170;   // 轉向快速
```

### PWM範圍
- 最小: 0
- 最大: 255

## 專案檔案結構

```
RC-Helium-Balloon-Blimp/
├── README.md                           # 項目說明（英文/中文）
├── platformio.ini                      # PlatformIO配置
├── sketch_may14a.ino                   # 主要草圖
├── src/
│   └── main.cpp                        # 主程式源碼
├── arduino/
│   └── sketch_may14a/
│       └── sketch_may14a.ino           # Arduino版本
└── docs/
    ├── progress-2026-05-22.md          # 階段進度報告
    └── progress-summary-2026.md        # 本文件
```

## GitHub提交日誌

| 提交ID | 信息 | 狀態 |
|---|---|---|
| `23c984c` | Separate English and Chinese documentation sections | ✅ main |
| `0e93481` | Make README bilingual | ✅ |
| `366c047` | Add date to progress report | ✅ |
| `95198ef` | Add differential motor test progress report | ✅ |
| `452175a` | Initial motor test project | ✅ |
| `df6b0e1` | feat: 完成單馬達藍牙遙控測試 | ✅ |

**目前分支**: main
**遠程狀態**: 最新（已同步）

## 已驗證功能

- ✅ ESP32-C3 可成功與DRV8833通訊
- ✅ GPIO控制引腳正常工作
- ✅ PWM速度控制有效
- ✅ 左馬達獨立控制
- ✅ 右馬達獨立控制
- ✅ 差分推力轉向功能
- ✅ 馬達保護電路有效

## 下一步計畫

待定

---

**工作區**: `g:\飛船專題_2026\vs code\RC-Helium-Balloon-Blimp`

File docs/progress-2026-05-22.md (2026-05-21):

# Progress Report - 2026-05-22

Date: 2026-05-22

## English

### Project

RC Helium Balloon Blimp motor-control prototype.

This stage focused on confirming that the ESP32-C3 SuperMini can control two 720 coreless motors through the DRV8833 motor driver. The firmware was upgraded from single-motor testing to two-motor differential thrust testing.

### Hardware Used

- ESP32-C3 SuperMini
- DRV8833 motor driver module
- Two 720 coreless motors
- 104 ceramic capacitors
- 100uF electrolytic capacitor
- External motor battery

### Wiring Status

The control wiring remains the same as the previous test:

| ESP32-C3 SuperMini | DRV8833 |
| --- | --- |
| GPIO4 | IN1 |
| GPIO5 | IN2 |
| GPIO6 | IN3 |
| GPIO7 | IN4 |
| 3V3 | EEP |
| GND | GND |

Motor and power wiring:

| DRV8833 | Connection |
| --- | --- |
| VCC | Motor battery positive |
| GND | Motor battery negative |
| OUT1, OUT2 | Left motor |
| OUT3, OUT4 | Right motor |

The ESP32-C3 GND, DRV8833 GND, and motor battery negative are connected together as a shared ground.

### Added Protection Components

| Component | Placement | Purpose |
| --- | --- | --- |
| 104 ceramic capacitor | Across the left motor terminals | Reduce motor electrical noise |
| 104 ceramic capacitor | Across the right motor terminals | Reduce motor electrical noise |
| 100uF electrolytic capacitor | Between DRV8833 VCC and GND | Stabilize motor power input |

The 104 ceramic capacitors do not have polarity. The 100uF electrolytic capacitor has polarity: positive to DRV8833 VCC and negative to DRV8833 GND.

### Firmware Update

The firmware was upgraded from individual motor testing to differential thrust testing.

Updated files:

- `src/main.cpp`
- `arduino/sketch_may14a/sketch_may14a.ino`
- `README.md`

The current firmware uses PWM speed control. PWM allows the motors to run at different thrust levels instead of only fully on or fully off.

Current speed settings:

```cpp
const int CRUISE_SPEED = 150;
const int TURN_SLOW_SPEED = 80;
const int TURN_FAST_SPEED = 170;
```

The PWM range is `0` to `255`.

### Current Test Sequence

1. Forward: left and right motors both run forward at speed `150` for 1.5 seconds.
2. Stop for 2 seconds.
3. Backward: left and right motors both run backward at speed `150` for 1.5 seconds.
4. Stop for 2 seconds.
5. Turn left: left motor runs at speed `80`, right motor runs at speed `170` for 1.5 seconds.
6. Stop for 2 seconds.
7. Turn right: left motor runs at speed `170`, right motor runs at speed `80` for 1.5 seconds.
8. Stop for 3 seconds.

### Test Result

The updated firmware was compiled and uploaded to the ESP32-C3 through PlatformIO on COM10.

- Compilation: successful
- Upload: successful
- Board detected as ESP32-C3
- Current program appeared to run normally during motor testing

The motors responded normally, so the basic dual-motor control stage is considered working.

### Important Notes

- Do not leave the test program running continuously for a long time.
- Disconnect the motor battery after confirming the test sequence.
- During early tests, do not install propellers.
- If the left and right turn directions are reversed, either swap motor wiring or adjust the `turnLeft()` and `turnRight()` speed values in the firmware.

### Next Steps

1. Confirm the 104 capacitors and 100uF capacitor are installed correctly.
2. Test the same sequence with the motors physically mounted on the blimp frame.
3. Confirm actual thrust direction with propellers installed carefully.
4. Tune `CRUISE_SPEED`, `TURN_SLOW_SPEED`, and `TURN_FAST_SPEED`.
5. Add remote-control logic after the motor behavior is stable.

## 中文

### 專案

RC 氦氣飛船馬達控制原型。

本階段主要確認 ESP32-C3 SuperMini 是否能透過 DRV8833 馬達驅動模組控制兩顆 720 空心杯馬達。同時將程式從單顆馬達測試升級成雙馬達差速推力測試。

### 使用硬體

- ESP32-C3 SuperMini
- DRV8833 馬達驅動模組
- 兩顆 720 空心杯馬達
- 104 陶瓷電容
- 100uF 電解電容
- 外接馬達電池

### 接線狀態

控制線維持上次測試的接法：

| ESP32-C3 SuperMini | DRV8833 |
| --- | --- |
| GPIO4 | IN1 |
| GPIO5 | IN2 |
| GPIO6 | IN3 |
| GPIO7 | IN4 |
| 3V3 | EEP |
| GND | GND |

馬達與電源接法：

| DRV8833 | 接法 |
| --- | --- |
| VCC | 馬達電池正極 |
| GND | 馬達電池負極 |
| OUT1, OUT2 | 左馬達 |
| OUT3, OUT4 | 右馬達 |

ESP32-C3 的 GND、DRV8833 的 GND、馬達電池負極已規劃接在一起，形成共地。

### 新增保護與穩定元件

| 元件 | 位置 | 作用 |
| --- | --- | --- |
| 104 陶瓷電容 | 並聯在左馬達兩端 | 降低馬達電氣雜訊 |
| 104 陶瓷電容 | 並聯在右馬達兩端 | 降低馬達電氣雜訊 |
| 100uF 電解電容 | 接在 DRV8833 VCC 與 GND 之間 | 穩定馬達電源輸入 |

104 陶瓷電容沒有正負極。100uF 電解電容有正負極，正極接 DRV8833 VCC，負極接 DRV8833 GND。

### 程式更新

本次將程式從單顆馬達測試升級成雙馬達差速推力測試。

更新檔案：

- `src/main.cpp`
- `arduino/sketch_may14a/sketch_may14a.ino`
- `README.md`

目前程式使用 PWM 速度控制。PWM 可以讓馬達以不同推力運轉，而不是只有全開或全關。

目前速度設定：

```cpp
const int CRUISE_SPEED = 150;
const int TURN_SLOW_SPEED = 80;
const int TURN_FAST_SPEED = 170;
```

PWM 數值範圍是 `0` 到 `255`。

### 目前測試流程

1. 前進：左右馬達都以速度 `150` 正轉 1.5 秒。
2. 停止 2 秒。
3. 後退：左右馬達都以速度 `150` 反轉 1.5 秒。
4. 停止 2 秒。
5. 左轉：左馬達速度 `80`，右馬達速度 `170`，持續 1.5 秒。
6. 停止 2 秒。
7. 右轉：左馬達速度 `170`，右馬達速度 `80`，持續 1.5 秒。
8. 停止 3 秒。

### 測試結果

已透過 PlatformIO 將更新後的程式編譯並燒錄到 COM10 上的 ESP32-C3。

- 編譯：成功
- 燒錄：成功
- 板子辨識為 ESP32-C3
- 馬達測試時目前看起來正常運作

兩顆馬達都有正常反應，因此目前可以視為雙馬達基本控制階段已經成功。

### 注意事項

- 不要讓測試程式長時間連續運轉。
- 確認測試流程後，請拔掉馬達電池。
- 初期測試時不要安裝螺旋槳。
- 如果左右轉方向相反，可以對調馬達線，或調整程式中的 `turnLeft()` 和 `turnRight()` 速度設定。

### 下一步

1. 確認 104 陶瓷電容和 100uF 電解電容安裝正確。
2. 將馬達固定到飛船架構上，再測試同樣流程。
3. 小心安裝螺旋槳後，確認實際推力方向。
4. 調整 `CRUISE_SPEED`、`TURN_SLOW_SPEED`、`TURN_FAST_SPEED`。
5. 馬達行為穩定後，再加入遙控控制邏輯。

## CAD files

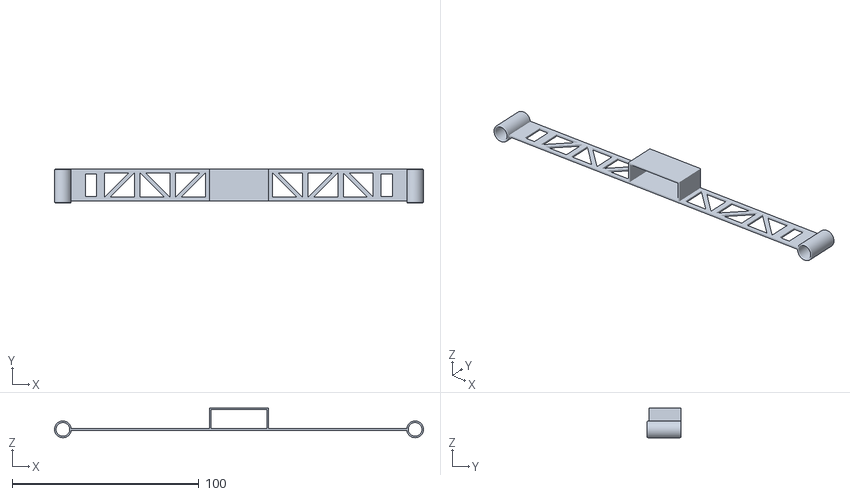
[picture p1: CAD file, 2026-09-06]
Helium Balloon Blimp Holder.stl
197.8 x 18.0 x 15.8

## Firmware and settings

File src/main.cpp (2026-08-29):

#include <Arduino.h>

#define CUSTOM_SETTINGS
#define INCLUDE_GAMEPAD_MODULE
#include <DabbleESP32.h>

// ESP32-C3 SuperMini + DRV8833 + Dabble GamePad control
// Power wiring:
// Battery - -> breadboard GND rail
// Battery + -> center pin of 3-pin slide switch
// Switch output -> breadboard VCC rail
// ESP32-C3 5V -> VCC rail, GND -> GND rail
// DRV8833 VCC -> VCC rail, GND -> GND rail, EEP -> VCC rail
// Signal wiring:
// GPIO4 -> DRV8833 IN1
// GPIO5 -> DRV8833 IN2
// GPIO6 -> DRV8833 IN3
// GPIO7 -> DRV8833 IN4

const int IN1 = 4;  // Left motor forward
const int IN2 = 5;  // Left motor backward
const int IN3 = 6;  // Right motor forward
const int IN4 = 7;  // Right motor backward

const int CRUISE_SPEED = 255;
const int TURN_FAST_SPEED = 255;
const int TURN_SLOW_SPEED = 120;
const int RAMP_SPEED = 15;

int currentLeftSpeed = 0;
int currentRightSpeed = 0;

void setMotor(int pinA, int pinB, int speed);
void drive(int targetLeft, int targetRight);
void stopMotors();
void handleGamePad();

void setup() {
  Serial.begin(115200);

  pinMode(IN1, OUTPUT);
  pinMode(IN2, OUTPUT);
  pinMode(IN3, OUTPUT);
  pinMode(IN4, OUTPUT);

  stopMotors();

  Dabble.begin("Innovation_Balloon");
  Serial.println("ESP32-C3 + DRV8833 Dabble control ready");
}

void loop() {
  Dabble.processInput();
  handleGamePad();
  delay(20);
}

void handleGamePad() {
  bool up = GamePad.isUpPressed();
  bool down = GamePad.isDownPressed();
  bool left = GamePad.isLeftPressed();
  bool right = GamePad.isRightPressed();

  int leftSpeed = 0;
  int rightSpeed = 0;

  if (up || down) {
    int direction = up ? 1 : -1;

    if (left) {
      leftSpeed = direction * TURN_SLOW_SPEED;
      rightSpeed = direction * TURN_FAST_SPEED;
    } else if (right) {
      leftSpeed = direction * TURN_FAST_SPEED;
      rightSpeed = direction * TURN_SLOW_SPEED;
    } else {
      leftSpeed = direction * CRUISE_SPEED;
      rightSpeed = direction * CRUISE_SPEED;
    }
  } else if (left) {
    leftSpeed = TURN_SLOW_SPEED;
    rightSpeed = TURN_FAST_SPEED;
  } else if (right) {
    leftSpeed = TURN_FAST_SPEED;
    rightSpeed = TURN_SLOW_SPEED;
  }

  drive(leftSpeed, rightSpeed);
}

void setMotor(int pinA, int pinB, int speed) {
  speed = constrain(speed, -255, 255);

  if (speed > 0) {
    analogWrite(pinA, speed);
    analogWrite(pinB, 0);
  } else if (speed < 0) {
    analogWrite(pinA, 0);
    analogWrite(pinB, -speed);
  } else {
    analogWrite(pinA, 0);
    analogWrite(pinB, 0);
  }
}

void drive(int targetLeft, int targetRight) {
  if (currentLeftSpeed < targetLeft) {
    currentLeftSpeed += RAMP_SPEED;
  } else if (currentLeftSpeed > targetLeft) {
    currentLeftSpeed -= RAMP_SPEED;
  }

  if (currentRightSpeed < targetRight) {
    currentRightSpeed += RAMP_SPEED;
  } else if (currentRightSpeed > targetRight) {
    currentRightSpeed -= RAMP_SPEED;
  }

  if (abs(currentLeftSpeed - targetLeft) <= RAMP_SPEED) {
    currentLeftSpeed = targetLeft;
  }
  if (abs(currentRightSpeed - targetRight) <= RAMP_SPEED) {
    currentRightSpeed = targetRight;
  }

  setMotor(IN1, IN2, currentLeftSpeed);
  setMotor(IN3, IN4, currentRightSpeed);
}

void stopMotors() {
  currentLeftSpeed = 0;
  currentRightSpeed = 0;

  setMotor(IN1, IN2, 0);
  setMotor(IN3, IN4, 0);
}

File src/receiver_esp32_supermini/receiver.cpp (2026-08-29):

#include <esp_now.h>
#include <WiFi.h>


// ==========================================
// 📍 硬體腳位定義 (ESP32-C3 SuperMini <-> DRV8833)
// ==========================================
const int IN1 = 4;  // 左馬達 (前進)
const int IN2 = 5;  // 左馬達 (後退)
const int IN3 = 6;  // 右馬達 (前進)
const int IN4 = 7;  // 右馬達 (後退)


// ==========================================
// ☁️ 動力參數 - 克服新馬達嗡嗡叫升級版
// ==========================================
// 🚀 關鍵修改 1：最低啟動推力直接從 95 起跳，跳過馬達會嗡嗡叫的低電壓死區！
const int START_POWER = 95;      
const int MAX_POWER = 150;        // 🚀 直線最高推力
const int JOYSTICK_DEADZONE = 120;// 🛡️ 搖桿飄移防護罩
const float STEERING_SENSITIVITY = 0.5; // 🧭 轉向靈敏度砍半，過彎更平滑


// ==========================================
// 🛡️ 軟啟動專用變數 (太空船漂浮感加速)
// ==========================================
int targetLeft = 0;
int targetRight = 0;
int currentLeft = 0;
int currentRight = 0;
const int RAMP_STEP = 10;         // ☁️ 雲朵提速
// 🚀 關鍵修改 2：起步瞬間直接給予的「踢力」，確保一開始就有 95 的力道讓馬達轉起來
const int DEAD_ZONE_JUMP = 95;    


unsigned long lastRecvTime = 0;


// ==========================================
// 📡 ESP-NOW 封包結構 + 驗證機制
// ==========================================
typedef struct struct_message {
  int x;           // 左右推力 (-255 到 255)
  int y;           // 前後推力 (-255 到 255)
  uint8_t checksum;// 🔒 簡單校驗和，確保資料完整無竄改
} struct_message;


struct_message myData;


// ==========================================
// 🔒 校驗和計算函數 (CRC8 簡易版)
// ==========================================
uint8_t calculateChecksum(int x, int y) {
  uint8_t sum = 0;
  sum += (x & 0xFF);           // X 的低位元組
  sum += ((x >> 8) & 0xFF);    // X 的高位元組
  sum += (y & 0xFF);           // Y 的低位元組
  sum += ((y >> 8) & 0xFF);    // Y 的高位元組
  return sum;
}


// ==========================================
// 📡 ESP-NOW 接收回調函數
// ==========================================
void OnDataRecv(const esp_now_recv_info *esp_now_info, const uint8_t *incomingData, int len) {
  memcpy(&myData, incomingData, sizeof(myData));
  lastRecvTime = millis();


  // 🔒 驗證校驗和 (防止訊號竄改)
  uint8_t expectedChecksum = calculateChecksum(myData.x, myData.y);
  if (myData.checksum != expectedChecksum) {
    Serial.println("⚠️ 警告：接收到不完整或被竄改的訊號，略過本次指令");
    return;  // 拒絕執行被竄改的命令
  }


  int throttle = myData.x;
  // 🛡️ 轉向數值直接套用靈敏度打折，並加上「負號 (-) 」來反轉左右方向！
  int steering = -(myData.y * STEERING_SENSITIVITY);


  // 過濾遙控器雜訊 (死區防護)
  if (abs(throttle) < JOYSTICK_DEADZONE) throttle = 0;
  if (abs(myData.y) < JOYSTICK_DEADZONE) steering = 0; // 注意看原始 Y 數值


  // 計算混控動力
  int leftPower = throttle + steering;
  int rightPower = throttle - steering;


  leftPower = constrain(leftPower, -255, 255);
  rightPower = constrain(rightPower, -255, 255);


  // 🚀 動力映射：確保只要有推動，推力絕對在 95 (START_POWER) 到 150 (MAX_POWER) 之間！
  if (leftPower > 0) targetLeft = map(leftPower, 0, 255, START_POWER, MAX_POWER);
  else if (leftPower < 0) targetLeft = map(leftPower, -255, 0, -MAX_POWER, -START_POWER);
  else targetLeft = 0;


  if (rightPower > 0) targetRight = map(rightPower, 0, 255, START_POWER, MAX_POWER);
  else if (rightPower < 0) targetRight = map(rightPower, -255, 0, -MAX_POWER, -START_POWER);
  else targetRight = 0;
}


void setup() {
  Serial.begin(115200);


  // 設定馬達控制腳位為輸出模式
  pinMode(IN1, OUTPUT);
  pinMode(IN2, OUTPUT);
  pinMode(IN3, OUTPUT);
  pinMode(IN4, OUTPUT);


  // 啟動時強制鎖死馬達策安全
  stopMotors();


  // 初始化 ESP-NOW
  WiFi.mode(WIFI_MODE_STA);
  if (esp_now_init() != ESP_OK) {
    Serial.println("ESP-NOW 初始化失敗！");
    return;
  }
  
  esp_now_register_recv_cb(OnDataRecv);


  Serial.println("==========================================");
  Serial.println("🚁 飛船 ESP32-C3 SuperMini");
  Serial.println("ESP-NOW 接收端已啟動 (含校驗和驗證)");
  Serial.println("==========================================");
  Serial.println("⏳ 等待遙控器訊號...");
}


void loop() {
  // 🛡️ 終極斷訊保護：超過 0.5 秒沒收到遙控器訊號，啟動安全煞車
  if (millis() - lastRecvTime > 500) {
    targetLeft = 0; 
    targetRight = 0;
    currentLeft = 0; 
    currentRight = 0;
    stopMotors();
  } else {
    // 正常連線時，執行平滑加速邏輯
    drive(targetLeft, targetRight);
  }
 
  // 控制迴圈更新頻率
  delay(20);
}


// ==========================================
// ⚙️ 底層驅動與平滑防護罩
// ==========================================
// 將正負數值的速度，轉換為雙腳位的 PWM 輸出 (純淨無雜訊版)
void setMotor(int pinA, int pinB, int speed) {
  speed = constrain(speed, -255, 255);


  if (speed == 0) {
    analogWrite(pinA, 0);
    analogWrite(pinB, 0);
  } else if (speed > 0) {
    analogWrite(pinB, 0);
    analogWrite(pinA, speed);
  } else {
    analogWrite(pinA, 0);
    analogWrite(pinB, -speed);
  }
}


// 平滑加速 (Soft-Start) 控制引擎
void drive(int tLeft, int tRight) {
  // 跨越死區機制：給馬達足夠的初始電壓踢力，避免嗡嗡叫
  if (tLeft != 0 && currentLeft == 0) currentLeft = (tLeft > 0) ? DEAD_ZONE_JUMP : -DEAD_ZONE_JUMP;
  if (tRight != 0 && currentRight == 0) currentRight = (tRight > 0) ? DEAD_ZONE_JUMP : -DEAD_ZONE_JUMP;


  // 緩步追蹤左馬達目標
  if (currentLeft < tLeft) currentLeft += RAMP_STEP;
  else if (currentLeft > tLeft) currentLeft -= RAMP_STEP;


  // 緩步追蹤右馬達目標
  if (currentRight < tRight) currentRight += RAMP_STEP;
  else if (currentRight > tRight) currentRight -= RAMP_STEP;


  // 防震盪貼齊
  if (abs(currentLeft - tLeft) <= RAMP_STEP) currentLeft = tLeft;
  if (abs(currentRight - tRight) <= RAMP_STEP) currentRight = tRight;


  // 輸出平滑後的真實速度到馬達
  setMotor(IN1, IN2, currentLeft);
  setMotor(IN3, IN4, currentRight);
}


// 緊急煞車與歸零
void stopMotors() {
  currentLeft = 0;
  currentRight = 0;
  setMotor(IN1, IN2, 0);
  setMotor(IN3, IN4, 0);
}

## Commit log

2026-05-17 feat: 完成單馬達藍牙遙控測試
2026-05-17 Initial motor test project
2026-05-21 Add differential motor test progress report
2026-05-25 update ESP32-C3 dual motor test firmware and project progress docs
    This commit updates the project from the earlier Dabble-based single-motor
    control sketch to the current ESP32-C3 + DRV8833 dual-motor differential
    thrust test setup.
    Firmware changes:
    - Replace the Dabble / GamePad control sketch with an automatic motor test loop.
    - Update motor control wiring to use four DRV8833 input pins:
    - GPIO4 -> IN1 for left motor control
    - GPIO5 -> IN2 for left motor control
    - GPIO6 -> IN3 for right motor control
    - GPIO7 -> IN4 for right motor control
    - Add PWM speed constants for the current test stage:
    - CRUISE_SPEED = 150
    - TURN_SLOW_SPEED = 80
    - TURN_FAST_SPEED = 170
    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
    [sketch_may14a.ino]
2026-05-28 docs: expand Dabble control wiring and progress report
    - Document full power wiring with battery, slide switch, VCC rail, and GND rail
    - Add ESP32-C3, DRV8833, EEP, signal wire, and motor output wiring details
    - Explain capacitor placement and purpose for 100uF and 104 capacitors
    - Expand firmware notes for Dabble GamePad control and smooth acceleration
    - Add testing checklist, troubleshooting table, and next-step plan
    - Update 2026-05-29 progress report with detailed daily progress
2026-08-29 Add dual control methods: Dabble app and ESP32 joystick with checksum validation
    - Added receiver_esp32_supermini/receiver.cpp: Flight control with CRC8 checksum
    - Added transmitter_esp32/transmitter.cpp: Remote control with MAC setup prompt
    - Added docs/CONTROL_METHODS.md: Comprehensive control guide
    - Security: Checksum validation and removed hardcoded MAC address
    - Safety: MAC binding and signal verification
    [receiver.cpp, transmitter.cpp]
2026-09-06 Create cad
